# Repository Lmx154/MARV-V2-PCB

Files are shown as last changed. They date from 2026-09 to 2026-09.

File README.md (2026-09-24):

# MARV V2 flight controller

A small RP2354B flight controller for rockets and drones: a 6-axis IMU, a high-g
accelerometer and a barometer on their own buses, native four-bit microSD
logging, USB-C, and an IO block for GPS, ELRS, a magnetometer and servos. Power
conversion from the pack stays **off the board**; the FC takes regulated 5 V (or
USB) and makes its own 3.3 V rails.

**License:** hardware/docs CC0, code 0BSD, no attribution required. Provided
as-is; see [LICENSE.md](LICENSE.md).

Open [MARV-V2.kicad_pro](MARV-V2.kicad_pro) in **KiCad 10**. The repository holds
the schematic and routed board, local footprints and 3D models, offline
datasheets, the design checks, and the input-power simulation. There
is no firmware here.

**Status (2026-09-23): customer-supplied assembly frame exported and verified.** ERC 0,
DRC 0 errors / 0 unconnected / 0 schematic-parity issues. There are 104 DRC
warnings, detailed in the [manufacturing check](reports/manufacturing-check.md).
The [72 × 72 mm manufacturing frame](reports/manufacturing-panel.md) supplies
rails/fiducials for Standard assembly. Review JLCPCB previews before ordering.

[Design specification](DESIGN_SPEC.md) · [GPIO pinout](PINOUT.md) ·
[Libraries](LIBRARIES.md) · [Datasheets](datasheets/README.md) ·
[JLCPCB DFM and routing](reports/jlc-dfm-routing.md) · [Working rules](AGENTS.md)

## The board

| Front | Back |
| :---: | :---: |
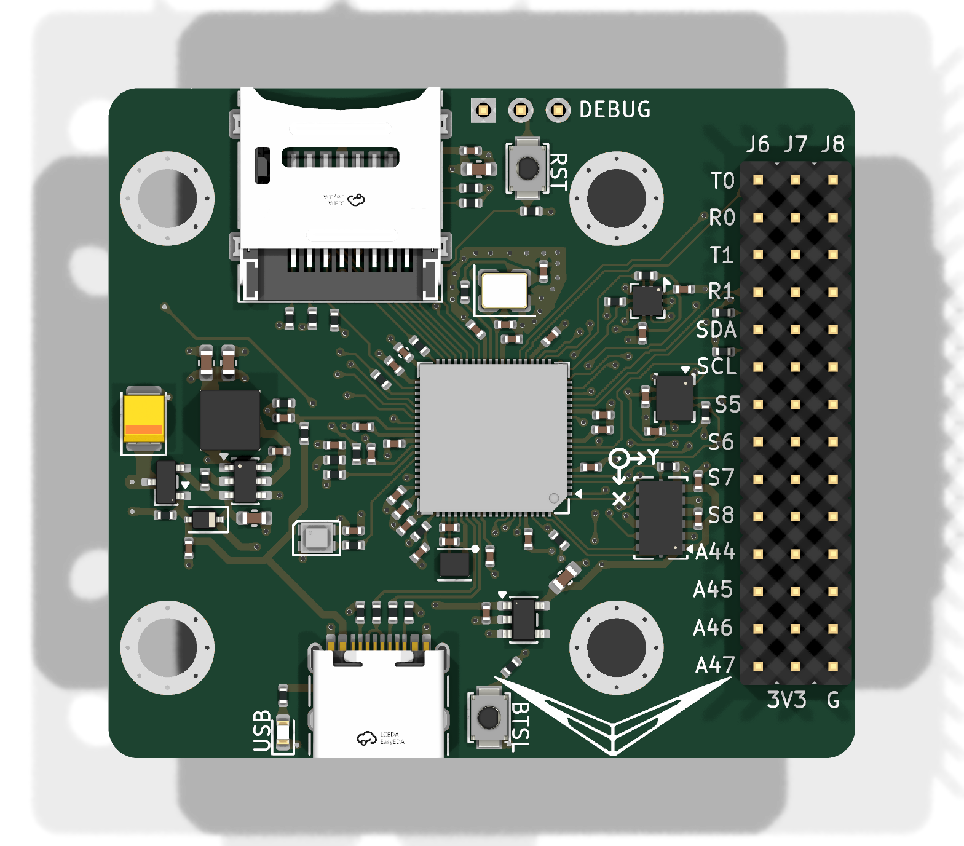
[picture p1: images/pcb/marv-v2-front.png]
MARV V2 PCB front view
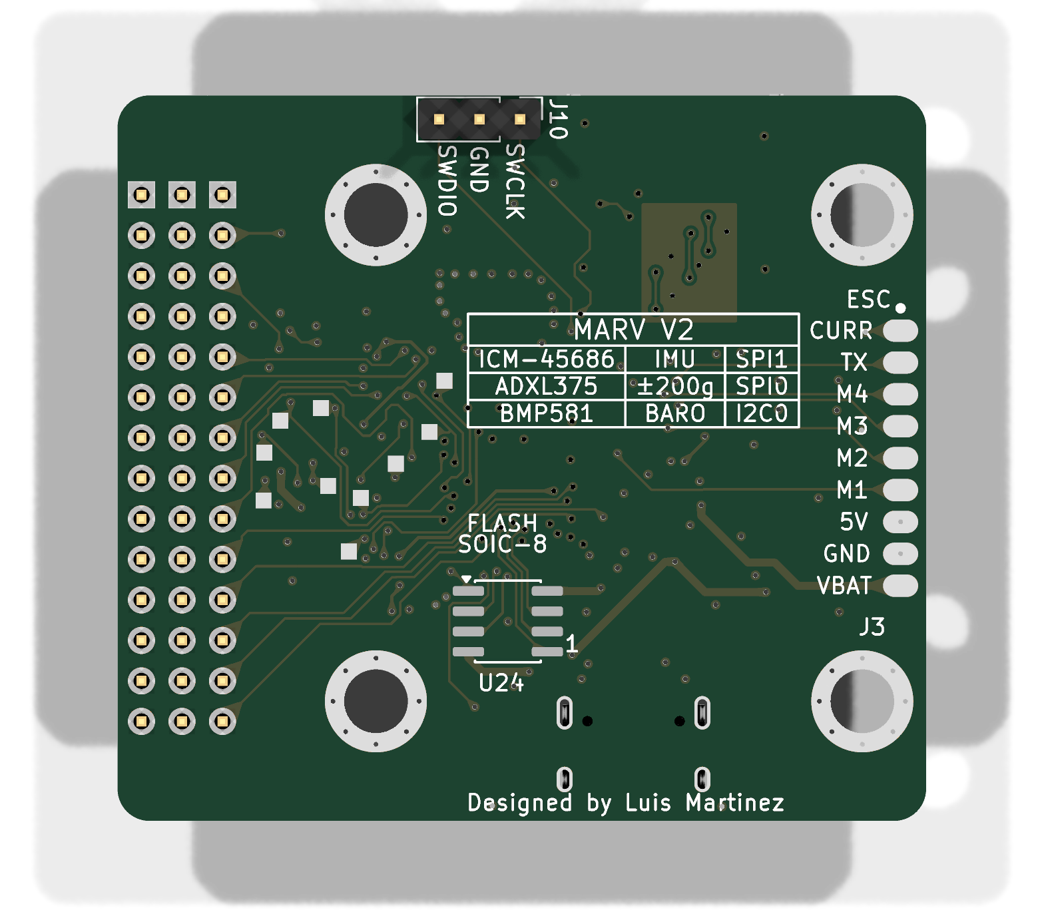
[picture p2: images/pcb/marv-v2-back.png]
MARV V2 PCB back view
|  |  |

3D renders of the saved PCB. Click either image for the full-resolution view.

To refresh both images after saving PCB changes, run:

```sh
python3 tools/render_pcb.py
```

Requires Python 3 and KiCad 10 with its 3D model libraries. The script renders
high-resolution PNGs into `images/pcb/` without modifying the design. Commit the
updated images alongside PCB changes to keep this gallery current.

| | |
|---|---|
| MCU | RP2354B (QFN-80, 2 MB in-package flash), 12 MHz crystal, USB-C device port, WS2812C status LED, RESET and BOOTSEL buttons, SWD header |
| Size / stack | 50.7 × 45.5 mm finished outline (72 × 72 mm manufacturing frame), four layers: F.Cu signals · In1 solid GND · In2 V3V3_SYS plane · B.Cu signals. 1.6 mm FR-4, 1 oz outer / 0.5 oz inner, green mask, HASL |
| Rules | 0.15 mm minimum track and clearance, one via size 0.60 / 0.30 mm, no blind/buried/micro vias — JLCPCB's standard four-layer tier with no paid options |
| Assembly | Front side SMT at JLCPCB (88 placements, 34 unique parts). Back side: ESC pad row J3, SWD header J10, unpopulated QSPI expansion socket U24, test points |
| Mounting | Four M3 grommet holes (4.0 mm) with GND rings |
| Connectors | J3 ESC pads (current, telemetry, PWM1–4, 5 V in, GND, VBAT), J4 USB-C, J6/J7/J8 IO block (14 rows × signal / power / GND), J10 SWD, J11 locking microSD |

## Sensor suite

Every sensor has its own bus; no clock or data net is shared between devices, so
each can be driven at its own rate and no transaction blocks another.

| Ref | Part | What it measures | Bus | Interrupts |
|---|---|---|---|---|
| U21 | InvenSense ICM-45686 | 6-axis IMU (gyro + accel), primary attitude source | hardware **SPI1**, exclusive | INT1, INT2 |
| U23 | Analog Devices ADXL375 | ±200 g accelerometer for launch / impact / hard landings | hardware **SPI0**, exclusive | INT1, INT2 |
| U22 | Bosch BMP581 | barometric altitude and temperature | hardware **I2C0**, address 0x46 | INT |
| J11 | Molex 47219-2001 microSD | flight log | PIO + DMA, native **four-bit SD** | — |

The three sensors run from the dedicated V3V3_ANA rail with their chip-select
and I²C pull-ups referenced to it, and all five interrupt lines land on
independent GPIOs. Layout follows the makers' notes: the BMP581 has no copper or
solder mask under its body (Bosch §8.2), and the inertial sensors sit close to
the MCU with short SPI runs. Exact GPIO numbers are in [PINOUT.md](PINOUT.md).

## Power architecture

```text
2S–6S pack → external 5 V / 3 A buck ─┐
1S 18650   → external 5 V boost ──────┘
                                      ↓ J3 5V_IN            USB-C VBUS
                                      Q1 (AO3401A)           D1 (1N5819WS)
                                      └────────── V5_SYS ────┘
                                                    ├─ AP63203 buck → V3V3_SYS  (MCU, microSD, IO block, LDO enable)
                                                    ├─ TPS7A2033 LDO → V3V3_ANA (ICM-45686, ADXL375, BMP581, ADC_AVDD)
                                                    └─ status LED
RP2354B on-chip switcher: V3V3_SYS → 1.1 V core (laid out per RP2350 datasheet §6.3.8)
Raw pack → J3 VBAT → 100k / 10k divider → ADC (sense only)
```

Nothing that moves is powered through the FC. Motors, servos and ESCs get only
their signal pins; the raw pack voltage arrives for measurement, not for use.
The full boundary table is in [DESIGN_SPEC.md](DESIGN_SPEC.md#sources-and-loads).

## Design decisions

Each of these was a choice with alternatives. The reasons are recorded so they
are not re-litigated by accident.

**External 5 V conversion, no onboard pack buck.** A 2S–6S buck or a 1S boost
already exists in every airframe this board goes into, and an onboard one would
add the hottest, noisiest, most layout-sensitive circuit to a 50 mm board.
The FC takes regulated 5 V and does nothing with the pack except measure it.
Battery charging, protection and cutoff belong to the external system.

**Q1/D1 OR for USB and external power — honestly specified.** A P-FET with its
gate on VBUS plus a Schottky lets the board run on the bench from USB alone and
in the air from the BEC. It does *not* guarantee that the BEC "wins" when both
are present: with USB connected the sources share through D1 and Q1's body
diode and V5_SYS sits lower. That is the circuit's real behaviour, it is what the
simulation shows, and the design accepts it rather than adding a priority mux.

**A separate LDO for the sensors, fed from 5 V.** The inertial sensors and the
barometer see a rail that is not the one the MCU, SD card and IO modules are
switching on. The TPS7A2033 takes its input from V5_SYS (headroom that a 3.3 V →
3.3 V filter cannot give) and its enable from V3V3_SYS, so the sensor rail comes
up after the digital rail. A passive filter was considered and rejected.

**Native four-bit SD over PIO instead of SPI mode.** Logging at flight rates
wants the bandwidth of four data lines and the standard SD command set, and the
RP2354B's PIO can run that bus without touching either hardware SPI block — so
SPI0 stays exclusive to the ADXL375 and SPI1 to the ICM-45686. The cost is six
GPIOs that must sit inside the PIO window (GPIO28–33), five 10 k pull-ups and a
22 Ω series damping resistor on the clock placed at the MCU pin.

**A locking microSD socket ("the latch").** J11 is a hinged-lid connector that is
closed and slid into a locked position over the card: a push-push socket can
eject a card under the shock and vibration of a launch or a hard landing, and a
lost log is the one failure a flight recorder must not have. The trade is that
this socket has no card-detect switch, so the former detect pin and its pull-up
were removed and firmware probes for the card.

**Core-regulator layout by the datasheet.** The RP2354B's 1.1 V core switcher
follows RP2350 datasheet §6.3.8 Figures 23–24: CIN/COUT (C39/C45) in a column
with the LX trace passing between their pads (0402 lands narrowed to a 0.50 mm
gap for that), the inductor's high-current loop closed on the top layer with one
ground connection through two adjacent vias, a copper cutout on In1 under the
inductor and LX net only, the AVDD RC filter, the recommended second 4.7 µF on
the core rail (C81) on the far side of the package, and the polarity-marked
Abracon inductor the datasheet specifies (orientation dot toward pad 2 / DVDD).

**Ordinary four-layer fabrication; spend the budget on components.** 0.15 mm
track/clearance, one 0.60 / 0.30 mm via, HASL, standard copper. The single
exception is a local 0.12 mm clearance rule around C39/C45 so LX can pass the
capacitor pads; that is still inside JLC's 3.5 mil four-layer capability and
costs nothing. No HDI, no filled vias, no impedance control: the USB link is
full-speed, and nothing else on the board is fast enough to need it.

**Through-hole headers shipped unpopulated.** J6–J8 (IO block) and J10 (SWD) are
2.54 mm headers the owner solders; JLC assembles the front SMT side only. J10 is
wired SWCLK–GND–SWDIO to match the Raspberry Pi Debug Probe's 3-pin cable.

**Three GPIOs deliberately unexposed.** GPIO26, 27 and 35 are left unconnected
so the IO block keeps a clean four-spare layout (GPIO44–47); the netlist checker
enforces that they stay that way.

## Validating the power input with simulation

The one thing the board cannot control is how power arrives, so that is the one
thing simulated. `tools/simulate_power_input.py` builds an ngspice deck from the
**saved schematic** (it checks the Q1/D1/C19 wiring before running) and drives
V5_SYS through seven cases: external 5 V only; USB only; both present; USB
plugged in while external stays; USB unplugged; external unplugged; and an
external-only load step. The pass criterion is explicit: the lowest V5_SYS seen
in any event window must stay above the AP63203's 3.8 V input minimum, or the
script exits 1.

```sh
python3 tools/simulate_power_input.py                       # default 0.5 A at V5_SYS
python3 tools/simulate_power_input.py --load 0.3 --usb-voltage 4.75
python3 tools/simulate_power_input.py --load 0.5 --external-load 1.0
```

Latest result ([simulations/RESULTS.md](simulations/RESULTS.md)): lowest event
voltage **4.269 V** during USB removal, margin 0.47 V over the floor; USB-only
operation settles at 4.32 V through D1. Assumptions are stated, not hidden:
0.05 Ω external source, 0.35 Ω USB source, a 0.5 A combined demand that is a
starting point rather than a measured budget, the vendor AO3401A model and a
hand-fitted 1N5819WS curve. It does **not** simulate the downstream regulators,
USB negotiation, sensor noise, layout parasitics or temperature — see
[simulations/README.md](simulations/README.md) for the boundary. Anything
beyond the OR is validated on hardware, not in SPICE.

## Verifying the design

Requirements: Python 3, KiCad 10 with its standard libraries, ngspice. Ordering exports use the installed Fabrication Toolkit plugin.

```sh
mkdir -p build/checks
kicad-cli sch erc --severity-all --exit-code-violations -o build/checks/erc.rpt MARV-V2.kicad_sch
kicad-cli sch export netlist --format kicadxml -o build/checks/netlist.xml MARV-V2.kicad_sch
python3 tools/check_power_netlist.py build/checks/netlist.xml   # rails, all 48 GPIOs, bus endpoints, pull-ups, retired refs
python3 tools/audit_footprints.py build/checks/netlist.xml     # footprint/model availability and pin coverage
python3 tools/dfm.py --check                                   # JLC profile drift (read-only)
kicad-cli pcb drc --schematic-parity --severity-error --severity-warning --format json -o build/dfm/drc.json MARV-V2.kicad_pcb
python3 -m unittest discover -s tests -v                       # DFM tool preservation tests
```

The JLCPCB profile (`config/dfm/jlcpcb.json` and the managed block in
`MARV-V2.kicad_dru`) is applied with `python3 tools/dfm.py --apply` with the PCB
editor closed; it edits only managed settings and never touches placement or
copper. Extra rules live outside the managed block. Netclasses: Signal 0.15 mm,
Default 0.20 mm, LocalPower 0.50 mm, Power 1.0 mm, USB 0.30 mm / 0.20 mm gap.

## Ordering

Use the installed [Fabrication Toolkit](https://github.com/bennymeg/Fabrication-Toolkit)
from KiCad's PCB Editor. Project settings are saved in
[fabrication-toolkit-options.json](fabrication-toolkit-options.json); no custom
Gerber, BOM or placement exporter is needed.

1. Open **MARV-V2-panel.kicad_pro** for the Standard assembly export. This is
   a saved manufacturing copy with customer-supplied rails. After circuit-design
   changes, update the original board, synchronize the manufacturing copy, and
   run the checks before exporting. See the [panel notes](reports/manufacturing-panel.md).
2. Click **Fabrication Toolkit → Generate**. The saved options enable automatic
   component translations and exclude DNP parts. The **User.1 V-cut option is on** for the manufacturing panel. Automatic zone
   refill, alternate outlines and plotting all active layers are **off**. Refill zones
   yourself in KiCad when copper changes require it, before the final DRC.
3. Upload the generated files:

   | JLCPCB step | File |
   | --- | --- |
   | PCB fabrication | `production/MARV-V2-panel.zip` (Gerbers and drills with rails) |
   | Assembly parts | `production/bom.csv` |
   | Assembly placement | `production/positions.csv` |

These three files were regenerated together from the manufacturing panel on
**2026-09-23**. The BOM and placements match the original board; the Gerbers
include the rails, routed channels, V-score annotations and fiducials;
the NPTH drills include tooling holes and the original USB locating holes. The local
`production/order-manifest.json` records source/output SHA-256 hashes, and
`production/SHA256SUMS` checks the three upload files. See the
[panel verification](reports/manufacturing-panel.md) for validation results
and remaining preview checks. Regenerate after any saved design change.

The initial order is **5 PCBs manufactured, 2 assembled on the top side** and
3 bare. Select **1 design, Single PCB, 4 layers, 1.6 mm, green mask, white silk,
HASL (with lead), standard copper and 0.30 mm minimum via holes**. Use
**Standard assembly** and **Edge Rails/Fiducials → Added by Customer**.
The 72 × 72 mm frame contains one finished PCB and uses two full-height
V-scores through its side connections, with no mouse-bite holes or added rail silk. It can be removed after delivery; check the quote no longer includes
JLC's rail-addition service charge.

The schematic's `LCSC` fields and native BOM/position exclusions define the
assembly selection. J6–J8 and J10 are owner-soldered headers; J3, H1–H4,
TP1–TP10 and the graphic footprints are board features; U24 is DNP. All are
omitted from assembly exports. This leaves **88 front-side placements using
34 distinct LCSC parts**. The plugin currently generates 84 BOM rows because
many component values include different descriptive notes; the part selections
are unchanged. JLC's parts-selection page provides current stock and pricing.

Automatic translations apply the plugin's package rotation corrections; they
are export corrections, not changes to the PCB layout. Review every placement
in JLC's preview, especially the custom sensor footprints and **L20: orientation
dot toward pad 2 / DVDD**. The first plugin export was checked against the
previous order files: all 88 part numbers and XY locations matched.

`production/` is generated and ignored by Git. The older `build/fab/`,
`build/assembly/` and `build/MARV-V2-gerbers.zip` outputs are superseded; use the
three plugin files above together. The former `tools/jlc/` scripts and duplicate
CSV inventories were retired; Git history retains them.

## Repository map

| Location | Content |
|---|---|
| `MARV-V2.kicad_*`, `*.kicad_sch` | Project, routed board, custom rules, and the schematic sheets (power OR / 3V3 / VBAT, MCU, IMU, high-g, baro, SD, USB & debug, IO block, QSPI expansion) |
| `DESIGN_SPEC.md`, `PINOUT.md` | Intended circuit and boundaries; every GPIO with its alternates |
| `config/dfm/` | Reviewed JLCPCB profile and custom-rule template |
| `tools/` | Netlist checker, footprint audit, DFM tool, input-power simulation, sheet relinker, netlist fingerprint, PCB image renderer |
| `MARV-V2-panel.kicad_*` | Saved one-board manufacturing frame for Standard assembly with customer-supplied rails |
| `fabrication-toolkit-options.json` | Native Fabrication Toolkit settings for JLCPCB order exports |
| `tests/` | Unit tests for the DFM tool's preservation guarantees |
| `simulations/` | The input-power SPICE deck, its README and the generated results |
| `MARV_Packages.pretty/`, `MARV_Packages.3dshapes/` | Local footprints and STEP models with provenance |
| `datasheets/` | Manufacturer PDFs and a source index |
| `reports/` | Decision and review records — see below |
| `production/`, `build/`, `.dfm-backups/`, `backups/` | Generated output and recovery copies; untracked |

Reports, newest first:

| Report | What it records |
|---|---|
| [manufacturing-panel.md](reports/manufacturing-panel.md) | Customer-supplied V-cut frame, current order package and panel verification |
| [manufacturing-check.md](reports/manufacturing-check.md) | Current manufacturing exports, source verification, DRC warnings and order handoff |
| [electrical-review.md](reports/electrical-review.md) | Review of the saved board before the core-regulator rework |
| [fabrication-cost-audit.md](reports/fabrication-cost-audit.md) | Why the board fits JLC's standard four-layer tier with no upcharges |
| [signal-trace-widths.md](reports/signal-trace-widths.md) | The 55 nets in the 0.15 mm Signal class |
| [jlc-dfm-routing.md](reports/jlc-dfm-routing.md) | JLC capability sources behind every installed constraint |
| [sd-connector-replacement.md](reports/sd-connector-replacement.md) | The locking microSD socket decision and what it removed |
| [communication-architecture.md](reports/communication-architecture.md) | The sensor/SD bus allocation as first made. Its GPIO numbers predate the later pin reorder; [PINOUT.md](PINOUT.md) is authoritative |

Git history keeps the obsolete revisions (onboard pack buck, power mux, buzzer,
earlier connectors); the cleanup baseline is commit `eafe903`. Placement and
routing are done by hand in KiCad and are never regenerated — see
[AGENTS.md](AGENTS.md).

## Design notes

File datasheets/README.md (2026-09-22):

# Component datasheets

Local copies of the manufacturer datasheet for every non-passive part on the board (ICs, discrete
semiconductors, the crystal, connectors/sockets with a specific vendor part, and modules). Purpose:
give any worker a fast, offline reference — `pdftotext <file>.pdf - | less` (or `pdfinfo`) instead of
re-fetching from the web on every question about pinout, decoupling or the application circuit.
Plain passives (R/L/C, ferrite beads), test points and mounting hardware are excluded; see
the schematic values / freshly generated `production/bom.csv` for those.

Two datasheets (`W25Q32JV.pdf`, `APS6404L.pdf`) both cover U24: it is one SOIC-8 socket that takes
either part (DNP by default; see `qspi_expansion.kicad_sch`).

| Refdes | Part | Manufacturer | File | Source URL | Date fetched | Relevant section/page |
|---|---|---|---|---|---|---|
| U20 | RP2354B (RP2350 family, on-package flash) | Raspberry Pi Ltd | `RP2350.pdf` | https://datasheets.raspberrypi.com/rp2350/rp2350-datasheet.pdf | 2026-09-17 | Sec 6.3.8 "External components and PCB layout requirements", p.453 (core-regulator L/C network) |
| U21 | ICM-45686 | TDK InvenSense | `ICM-45686.pdf` | https://www.lcsc.com/datasheet/lcsc_datasheet_2411220643_TDK-InvenSense-ICM-45686_C22459454.pdf (manufacturer page is a gated download form; fetched the LCSC-hosted copy) | 2026-09-17 | Bypass-capacitor table (VDD/VDDIO, 0.1 uF X7R), p.34 |
| U22 | BMP581 | Bosch Sensortec | `BMP581.pdf` | https://www.bosch-sensortec.com/media/boschsensortec/downloads/datasheets/bst-bmp581-ds004.pdf | 2026-09-17 | Pin-out, Figure 22, p.46 |
| U23 | ADXL375BCCZ | Analog Devices | `ADXL375.pdf` | https://www.analog.com/media/en/technical-documentation/data-sheets/ADXL375.PDF | 2026-09-17 | "Power Supply Decoupling", p.26 |
| U7 | AP63203WU-7 | Diodes Incorporated | `AP63203.pdf` | https://www.diodes.com/assets/Datasheets/AP63200-AP63201-AP63203-AP63205.pdf | 2026-09-17 | Figure 21 "Typical Application Circuit of AP63203/AP63205", p.9 (external-component table referenced as "Table 2" in `tools/build_power.py`) |
| U12 | TPS7A2033PDBVR | Texas Instruments | `TPS7A2033.pdf` | https://www.ti.com/lit/ds/symlink/tps7a20.pdf | 2026-09-17 | Sec 7.2 "Typical Application" / Figure 7-4, p.30; Sec 7.4 "Layout", p.31 |
| U24 (fit option A) | W25Q32JVSNIQ (32 Mbit QSPI NOR) | Winbond | `W25Q32JV.pdf` | https://www.winbond.com/resource-files/W25Q32JV%20RevJ%2012242024%20Plus.pdf | 2026-09-17 | Figure 1a, 8-pin SOIC 150-mil pin assignment (package code SN), p.6 |
| U24 (fit option B) | APS6404L-SQN-SN (8 MB QSPI PSRAM) | AP Memory | `APS6404L.pdf` | https://www.apmemory.com/tw/downloadFiles/0324112120g3605268 | 2026-09-17 | Table 1 "Ordering Information" (confirms `-SQN-SN` suffix), p.7 |
| D20 | WS2812C-2020-V1 | Worldsemi | `WS2812C-2020.pdf` | https://www.lcsc.com/datasheet/lcsc_datasheet_2202221130_Worldsemi-WS2812C-2020-V1_C2976072.pdf (LCSC-hosted) | 2026-09-17 | Features / pin function / reflow profile, p.1-2 |
| Q1 | AO3401A | Alpha & Omega Semiconductor | `AO3401A.pdf` | https://www.aosmd.com/pdfs/datasheet/AO3401A.pdf | 2026-09-17 | Pin configuration and electrical characteristics table, p.1-2 |
| D1 | 1N5819WS | Guangdong Hottech | `1N5819WS.pdf` | https://www.lcsc.com/datasheet/lcsc_datasheet_Guangdong-Hottech-1N5819WS_C191023.pdf (LCSC-hosted) | 2026-09-17 | Electrical characteristics (VF, IR), p.1-2 |
| Y1 | 12 MHz TAXM12M4RFBCCT2T | Shenzhen Yajingxin Electronics | `TAXM12M4RFBCCT2T.pdf` | https://www.lcsc.com/product-detail/C133337.html (manufacturer spec sheet, LCSC-hosted) | 2026-09-17 | Specification table (12.000 MHz, CL = 12 pF), p.1 |
| J4 | USB-C receptacle TYPE-C-31-M-12 | Korean Hroparts Elec (HRO Electronics) | `TYPE-C-31-M-12.pdf` | https://www.lcsc.com/product-detail/C165948.html (manufacturer drawing, LCSC-hosted) | 2026-09-17 | Pinout table (A1-A12/B1-B12) and PCB land pattern, p.1 |
| J11 | Molex 47219-2001 / 472192001, C164170, locking hinged microSD | Molex | `472192001.pdf`; `472192001-drawing.pdf` | https://www.es.co.th/Schemetic/PDF/472192001.PDF (Molex part datasheet, generated 2025-04-07); https://cdn.promelec.ru/upload/items/2020/09/01/472192001_sd.pdf (Molex drawing mirror) | 2026-09-17 | Datasheet pp.1–3: hinge type, 8 contacts, no detect switch; drawing p.1: pad layout and pin numbering |
| SW1, SW2 | B3U-1000P tactile switch | Omron | `B3U-1000P.pdf` | https://omronfs.omron.com/en_US/ecb/products/pdf/en-b3u.pdf | 2026-09-17 | Ratings and characteristics table, p.1-2 |

## UNKNOWN

None — all 15 non-passive parts resolved to a verified manufacturer (or manufacturer-authorized
distributor mirror) PDF. Three parts required a fallback from the manufacturer's own site to an
LCSC-hosted copy after the manufacturer link was gated or blocked outbound `curl`/`wget` requests
(see the Source URL column: ICM-45686, WS2812C-2020, 1N5819WS, TAXM12M4RFBCCT2T and
TYPE-C-31-M-12 all use the LCSC-hosted PDF; every other file is the manufacturer's own domain).
Every file was confirmed to start with `%PDF`, exceed 50 kB (the smallest are the two single-sheet
mechanical connector drawings, `TYPE-C-31-M-12.pdf` at ~116 kB and `104031-0811.pdf` at ~100 kB), and
contain the exact part number on an early page via `pdftotext`/`pdfinfo` (and, for `TYPE-C-31-M-12.pdf`,
a rendered-page visual check since that drawing is almost all vector graphics with little extractable
text).

## Locking microSD replacement

J11 now uses Molex 47219-2001 / LCSC C164170. Its manufacturer datasheet and
one-page mechanical drawing are stored above. Both files were verified as PDFs.
The official drawing endpoint timed out during download, so manufacturer content
was retrieved from distributor mirrors. Official drawing URL:
https://www.molex.com/content/dam/molex/molex-dot-com/products/automated/en-us/salesdrawingpdf/472/47219/472192001_sd.pdf

Molex describes the hinged lid and slide-to-lock sequence in its card-socket
brochure: https://www.content.molex.com/dxdam/literature/987651-8263.pdf
The old `104031-0811.pdf` is retained while the saved PCB still uses that socket's
land pattern. Remove it with the old footprint after the owner updates J11.

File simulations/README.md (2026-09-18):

# Input-power simulation

Run `python3 tools/simulate_power_input.py` from the project root. Results are in
[RESULTS.md](RESULTS.md). Requires Python, KiCad CLI and ngspice; no Python packages.

The boundary is external regulated 5 V plus USB, through Q1/D1, to V5_SYS.
External power is either a 2S–6S-to-5 V, 3 A buck or a 1S-18650-to-5 V boost.
Both converters live off-board. Neither raw battery voltage nor charging enters this model.

One deck, [power_input.cir](power_input.cir), runs seven cases: external only,
USB only, both present, USB insertion, USB removal, external removal, and an
external-powered load step. It checks the saved schematic's key power connections
before running. Downstream electronics are one explicit current demand at V5_SYS;
the simulation does not implement fictional buck or LDO control loops.

Default demand is **0.5 A at V5_SYS**, an assumption that can be changed:

```sh
python3 tools/simulate_power_input.py --load 0.3
python3 tools/simulate_power_input.py --load 0.5 --external-load 1.0
python3 tools/simulate_power_input.py --usb-voltage 4.75
```

`--external-load` is additional electronics demand on 5V_IN, before the OR.
The external source's 3 A rating is its capacity, not the board's assumed draw.
Source resistances are explicitly assumed: external 0.05 ohm, USB 0.35 ohm.
The external boost's output rating and both converters' transient behavior need
actual module specifications or measurements; cell current ratings do not supply those.

The report shows V5_SYS voltage and source/reverse currents. The 3.8 V comparison
is the AP63203's specified minimum input, not a pass/fail test for the whole board.
Exit 1 means a simulated event falls below that input range. Solver/check errors
also fail the command. Exact generated decks, logs and waveform tables stay in a
printed temporary directory; they do not multiply tracked project files.

Q1 uses the existing AOS model. D1 uses the existing hand-fitted forward curve;
its temperature-dependent leakage is not bounded. Capacitors are nominal and the
white LED curve is approximate. Source current limiting, charging, cell cutoff,
USB negotiation, regulator outputs, noise, layout and thermal behavior are outside scope.
In particular, this simulation cannot decide whether sensor supplies need an LDO.

Historical simulation revisions are available in Git history. Only the current
input-network deck and its required models are maintained here.

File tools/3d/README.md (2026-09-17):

# STEP model inspection

`bbox.py` is the reusable FreeCAD helper for inspecting model dimensions and
alignment while changing footprints or importing replacement models.

```sh
/snap/bin/freecad.cmd -c tools/3d/bbox.py -- FILE.step </dev/null
```

With no STEP arguments it inspects local models in `MARV_Packages.3dshapes/`
and its `_incoming/` directory. It prints bounding coordinates, dimensions,
centers, solid counts and face counts without changing the files.

Requires FreeCAD. Keep inputs under the repository for the snap's filesystem
access. KiCad model and footprint Y axes differ; see the script's coordinate
notes when interpreting offsets.

The four one-time package generators have been removed. Their STEP assets and
[provenance](../../MARV_Packages.3dshapes/PROVENANCE.md) remain available.

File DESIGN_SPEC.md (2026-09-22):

# MARV V2: intended circuit

The goal is a simple flight controller for rockets/drones, using external power
conversion and familiar flight-controller circuitry. The supplied madflight
FC3v2 reference is a simplicity/layout reference, not a requirement to copy every
component. Owner-confirmed decisions in this document supersede older design notes.

## Power architecture

```text
2S–6S pack → external 5 V / 3 A buck ─┐  alternative external sources
1S 18650 → external 5 V boost ────────┘
                                    ↓
                              J3.7 / 5V_IN (BEC input only; no header row)
                                    ↓ Q1
USB VBUS ──────────────────── D1 ──→ V5_SYS
                                      ├─ AP63203 buck → V3V3_SYS
                                      │                  ├─ MCU, microSD, optional QSPI
                                      │                  ├─ GPS/ELRS/MAG and spare IO
                                      │                  └─ LDO enable
                                      ├─ TPS7A2033 LDO → V3V3_ANA → onboard sensors / ADC_AVDD
                                      └─ RGB status LED

Raw battery → J3.9 / VBAT → 100k / 10k divider → MCU voltage measurement
```

The analog LDO takes its **input from V5_SYS**, not from the 3.3 V buck.
Its **enable** comes from V3V3_SYS. This retains headroom for a regulated 3.3 V
sensor supply. The owner chose to retain this small stage after considering a
passive filter. External daughterboard demand stays off the analog rail.

No onboard pack buck, battery charger, battery current shunt, power mux IC, or
custom regulator-control simulation is required. Battery charging and converter
protection/cutoff belong to the external system.

## Sources and loads

| Item | Agreed boundary |
| --- | --- |
| 2S–6S option | External buck supplies regulated 5 V, rated 3 A. The FC receives its output. |
| 1S option | External boost supplies regulated 5 V. The cell is not wired directly to the OR. Boost output rating and transient behavior are not yet specified. |
| 18650, owner-provided specifications | 4.2 V charged / 3.6 V nominal / 2.5 V discharge cutoff; charge 3 A standard / 9 A maximum with 60 °C cutoff; discharge 30 A continuous with 80 °C cutoff / 36 A maximum rating. These are external-system specifications, not functions implemented by this PCB. |
| USB | VBUS supplies the FC through D1. USB current availability must cover the attached electronics; the simulation does not implement negotiation or a host current limit. |
| System 3.3 V | MCU, storage and external module/IO power. The AP63203 is a 2 A regulator; that rating is not a measured board load budget. |
| Sensor 3.3 V | ICM-45686, BMP581, ADXL375 and MCU ADC_AVDD, supplied by U12. |
| Actuators | Owner clarified 2026-09-18: no servos, motors or actuators are powered from FC pads. Only their PWM/control signals use the FC. Existing 5V_IN pad connections remain, but no actuator current is included in the FC trace budget. |

The new simulation uses an explicit **0.5 A combined demand at V5_SYS** as a
starting assumption. This is neither 0.5 A on each downstream rail nor a demand
for the external converter to deliver its full 3 A rating. Choose actual module
loads before assigning a final system/USB budget. A daughterboard having its own
LDO does not by itself establish that its power input accepts 3.3 V; that input
range remains a module-selection requirement.

Expected external electronics may include four ToF sensors, several lidar modules,
GPS and an ELRS radio. Their exact voltage requirements and simultaneous peak
current remain to be established. The routing defaults and fabrication constraints
are documented in [JLCPCB DFM and routing](reports/jlc-dfm-routing.md).

## OR behavior

Q1 is an AO3401A: drain on 5V_IN, source on V5_SYS, gate on USB_VBUS.
D1 is a 1N5819WS: anode on USB_VBUS, cathode on V5_SYS. C19 is 100 uF
on the external input, upstream of Q1.

With USB absent, Q1's gate discharges and its channel carries the external supply.
With USB present, Q1 can be off and the sources can share through D1 and Q1's
body diode. **There is no guaranteed BEC priority or lossless switchover.**
A lower V5_SYS when USB is connected is consistent with this circuit; the old
expectation that the BEC always wins through Q1's low-resistance channel was wrong.

The USB-only path does not intentionally feed external 5V_IN. 5V_IN reaches no
header row: all fourteen J7 power pins are V3V3_SYS, so every IO block module can
operate on USB alone. Model leakage is
not a guarantee of zero reverse current under every temperature and source condition.

## Connectors

J3 pads 1–9: **CURR, TX, M4, M3, M2, M1, 5V_IN, GND, VBAT**.
VBAT is sense-only. ESC current is read from its analog output; the FC has no
propulsion-current pass-through or shunt. J10 is the SWD 1x03 2.54 mm header (SWCLK, GND, SWDIO — Debug Probe order).

For the IO block, each row has J6 = signal, J7 = power, J8 = ground:

| Rows | Signals | J7 supply |
| --- | --- | --- |
| 1–2 | GPS UART | V3V3_SYS |
| 3–4 | ELRS UART | V3V3_SYS |
| 5–6 | Magnetometer I2C | V3V3_SYS |
| 7–10 | PWM5–8, servo signals only | V3V3_SYS |
| 11–14 | GPIO44–47, spare IO | V3V3_SYS |

All signal IO is 3.3 V logic. J3 carries PWM1–4 to the ESC.
See [PINOUT.md](PINOUT.md) for individual MCU assignments.

## Sensor and storage communication

ADXL375 has exclusive hardware SPI0 (SCK GPIO2, MOSI GPIO3, MISO GPIO4, CS GPIO14).
ICM-45686 has exclusive hardware SPI1 (SCK GPIO10, MOSI GPIO11, MISO GPIO8, CS GPIO7).
Both selects have 10k pull-ups to the sensors' V3V3_ANA supply. Clock and data
signals have no pull resistors. ADXL INT1/INT2 use GPIO1/21; ICM INT1/INT2 use
GPIO6/18. All interrupt nets remain independent.

BMP581 uses I2C0 (SCL GPIO9, SDA GPIO12), each with a 4.7k pull-up to V3V3_ANA.
CSB is tied to VDDIO and SDO/ADDR to GND, selecting I2C address 0x46. BARO_INT
uses GPIO13. Existing sensor decoupling and power circuitry are retained.

microSD uses PIO + DMA native four-bit SD: DAT0–DAT3 GPIO28–31, CLK GPIO32,
CMD GPIO33, on the MCU's top-left corner facing J11. All six signals need the
PIO GPIO16–47 window, which the LED and ESC PIO signals already require. CMD
and all four data lines have 10k external pull-ups to V3V3_SYS. GPIO32 drives
SD_CLK through R58, 22 ohm nominal (0–33 ohm tuning range), to be placed next
to the MCU pin. There is no clock pull resistor. J11 is the Molex 47219-2001 / C164170 locking hinged-lid connector. It has no
card-detect switch; R41 is removed.
LED_DATA is on GPIO43. The ESC signals are ordered on the MCU's left edge to
match J3 top to bottom: ESC_TELEM_RX GPIO34, PWM4–PWM1 GPIO36–39, then
CURR_SENSE on ADC1 (GPIO41) and VBAT_SENSE on ADC2 (GPIO42); VBUS_SENSE stays
on ADC0. GPIO26, GPIO27 and GPIO35 are the unexposed spares. External connector
assignments are retained. See [PINOUT.md](PINOUT.md) for every GPIO and routing priorities.

This is a hardware allocation; no firmware is implemented. The board carries
these nets and parts as routed (2026-09-22).

## Board and validation scope

Owner cost requirement (2026-09-21): keep ordinary four-layer fabrication and
spend the budget on components. Retain 0.15 mm minimum traces/clearance,
0.60/0.30 mm through vias, standard 1.6 mm FR-4 and copper weights, green mask,
and the selected HASL finish. Do not introduce precision drills, HDI vias,
resin-filled/capped vias or other paid fabrication upgrades to resolve routing
congestion. See [signal widths](reports/signal-trace-widths.md) and the
[fabrication cost audit](reports/fabrication-cost-audit.md). Final CAM acceptance
and the actual quote remain required; project settings alone cannot guarantee price.

RP2354B MCU; ICM-45686 IMU; BMP581 barometer; ADXL375 high-g sensor;
microSD; optional unpopulated backside QSPI expansion. Four copper layers,
front-side SMT assembly, with backside solder pads/test points and the DNP
expansion land. Existing placement is retained. The owner will route the board manually in KiCad. Agents must not route,
autoroute, stitch planes or rebuild the layout.

The active simulation checks **power arriving at V5_SYS only**. It does not
predict sensor noise, regulator-loop stability, enclosure temperature or flight
performance. See [simulation results](simulations/RESULTS.md).

Routing and DRC are complete (2026-09-22: 0 errors, 0 unconnected, 0 parity).
Remaining work is off the board: confirm physical ESC pad pitch; select the
external converters and compatible 3.3 V modules; review JLC assembly rotations
in the ordering preview; then measure source transitions, supply noise during
module/SD activity, and temperatures on hardware. These checks do not mandate
additional circuit features unless they reveal an actual problem.

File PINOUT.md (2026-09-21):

# MARV V2 GPIO reference

The schematic records the wiring. Keep this reference and `tools/check_power_netlist.py` aligned
when changing GPIOs. Power assignments
for the IO block are in [DESIGN_SPEC.md](DESIGN_SPEC.md).

Source: RP2350 Datasheet, Section 1.2.3, Table 3 "General Purpose Input/Output (GPIO) Bank 0 Functions"
(F1 SPI, F2 UART, F3 I2C, F4 PWM, F5 SIO, F6-F8 PIO0/1/2, F9 clock/QMI/trace, F10 USB, F11 UART aux).
ADC0-7 are GPIO40-47 on the RP2350B/RP2354B (QFN-80) only. All GPIO are 3.3 V, not 5 V tolerant.

External IO leaves the board on the J6/J7/J8 IO block (right front edge, signal/power/GND columns), plus
two solder-pad rows on the back (B.Cu): the ESC pad row J3 and the DBG pads J10.

## Table A — every GPIO

| GPIO | Net | Used as | Datasheet alternates (F1 SPI / F2 UART / F3 I2C / F4 PWM / F9-F11) | Status |
| --- | --- | --- | --- | --- |
| 0 | FLASH_CS1 | QMI CS1n (F9) | SPI0 RX, UART0 TX, I2C0 SDA, PWM0 A, USB OVCUR DET | assigned (flash/PSRAM socket U24) |
| 1 | ADXL_INT1 | GPIO input (ADXL INT1) | SPI0 CSn, UART0 RX, I2C0 SCL, PWM0 B, USB VBUS DET | assigned |
| 2 | ADXL_SCK | SPI0 SCK (F1) | PWM1 A, SPI0 SCK, UART0 CTS, I2C1 SDA, USB VBUS EN, UART0 TX (F11) | assigned |
| 3 | ADXL_MOSI | SPI0 TX (F1) | PWM1 B, SPI0 TX, UART0 RTS, I2C1 SCL, USB OVCUR DET, UART0 RX (F11) | assigned |
| 4 | ADXL_MISO | SPI0 RX (F1) | PWM2 A, SPI0 RX, UART1 TX, I2C0 SDA, USB VBUS DET | assigned |
| 5 | PWM8 | PWM2 B (F4) | SPI0 CSn, UART1 RX, I2C0 SCL, USB VBUS EN | assigned (servo S8) |
| 6 | ICM_INT1 | GPIO input (ICM INT1) | I2C1 SDA, SPI0 SCK, UART1 CTS, PWM3 A, USB OVCUR DET, UART1 TX (F11) | assigned |
| 7 | ICM_CS | GPIO (ICM CS) | I2C1 SCL, SPI0 TX, UART1 RTS, PWM3 B, USB VBUS DET, UART1 RX (F11) | assigned |
| 8 | ICM_MISO | SPI1 RX (F1) | UART1 TX, I2C0 SDA, PWM4 A, QMI CS1n, USB VBUS EN | assigned |
| 9 | BARO_SCL | I2C0 SCL (F3) | UART1 RX, SPI1 CSn, I2C0 SCL, PWM4 B, USB OVCUR DET | assigned |
| 10 | ICM_SCK | SPI1 SCK (F1) | PWM5 A, UART1 CTS, I2C1 SDA, USB VBUS DET, UART1 TX (F11) | assigned |
| 11 | ICM_MOSI | SPI1 TX (F1) | PWM5 B, UART1 RTS, I2C1 SCL, USB VBUS EN, UART1 RX (F11) | assigned |
| 12 | BARO_SDA | I2C0 SDA (F3) | UART0 TX, SPI1 RX, I2C0 SDA, PWM6 A, CLOCK GPIN0, USB OVCUR DET | assigned |
| 13 | BARO_INT | GPIO in | UART0 RX, SPI1 CSn, I2C0 SCL, PWM6 B, CLOCK GPOUT0, USB VBUS DET | assigned |
| 14 | ADXL_CS | GPIO (ADXL CS) | PWM7 A, SPI1 SCK, UART0 CTS, I2C1 SDA, CLOCK GPIN1, USB VBUS EN, UART0 TX (F11) | assigned |
| 15 | PWM7 | PWM7 B (F4) | SPI1 TX, UART0 RTS, I2C1 SCL, CLOCK GPOUT1, USB OVCUR DET, UART0 RX (F11) | assigned (servo S7) |
| 16 | ELRS_RX | UART0 TX (F2) | SPI0 RX, I2C0 SDA, PWM0 A, USB VBUS DET | assigned (J6 R1) |
| 17 | ELRS_TX | UART0 RX (F2) | SPI0 CSn, I2C0 SCL, PWM0 B, USB VBUS EN | assigned (J6 T1) |
| 18 | ICM_INT2 | GPIO input (ICM INT2) | SPI0 SCK, UART0 CTS, I2C1 SDA, PWM1 A, USB OVCUR DET, UART0 TX (F11) | assigned |
| 19 | PWM6 | PWM1 B (F4) | SPI0 TX, UART0 RTS, I2C1 SCL, QMI CS1n, USB VBUS DET, UART0 RX (F11) | assigned (servo S6) |
| 20 | PWM5 | PWM2 A (F4) | SPI0 RX, UART1 TX, I2C0 SDA, CLOCK GPIN0, USB VBUS EN | assigned (servo S5) |
| 21 | ADXL_INT2 | GPIO input (ADXL INT2) | SPI0 CSn, UART1 RX, I2C0 SCL, PWM2 B, CLOCK GPOUT0, USB OVCUR DET | assigned |
| 22 | MAG_SDA | I2C1 SDA (F3) | SPI0 SCK, UART1 CTS, PWM3 A, CLOCK GPIN1, USB VBUS DET, UART1 TX (F11) | assigned (J6 SDA) |
| 23 | MAG_SCL | I2C1 SCL (F3) | SPI0 TX, UART1 RTS, PWM3 B, CLOCK GPOUT1, USB VBUS EN, UART1 RX (F11) | assigned (J6 SCL) |
| 24 | GPS_RX | UART1 TX (F2) | SPI1 RX, I2C0 SDA, PWM4 A, CLOCK GPOUT2, USB OVCUR DET | assigned (J6 R0) |
| 25 | GPS_TX | UART1 RX (F2) | SPI1 CSn, I2C0 SCL, PWM4 B, CLOCK GPOUT3, USB VBUS DET | assigned (J6 T0) |
| 26 | — (unexposed spare, no-connect) | GPIO | SPI1 SCK, UART1 CTS, I2C1 SDA, PWM5 A, USB VBUS EN, UART1 TX (F11) | spare, not exposed (no-connect). Was SD_CLK_MCU; the SD bus moved to GPIO28–33 so it meets J11 from the MCU's top-left corner |
| 27 | — (unexposed spare, no-connect) | GPIO | SPI1 TX, UART1 RTS, I2C1 SCL, PWM5 B, USB OVCUR DET, UART1 RX (F11) | spare, not exposed (no-connect). Was SD_CMD |
| 28 | SD_DAT0 | PIO native SD DAT0 | SPI1 RX, UART0 TX, I2C0 SDA, PWM6 A, USB VBUS DET | assigned |
| 29 | SD_DAT1 | PIO native SD DAT1 | SPI1 CSn, UART0 RX, I2C0 SCL, PWM6 B, USB VBUS EN | assigned |
| 30 | SD_DAT2 | PIO native SD DAT2 | SPI1 SCK, UART0 CTS, I2C1 SDA, PWM7 A, USB OVCUR DET, UART0 TX (F11) | assigned |
| 31 | SD_DAT3 | PIO native SD DAT3 | SPI1 TX, UART0 RTS, I2C1 SCL, PWM7 B, USB VBUS DET, UART0 RX (F11) | assigned |
| 32 | SD_CLK_MCU | PIO native SD clock, through R58 to SD_CLK | SPI0 RX, UART0 TX, I2C0 SDA, PWM8 A, USB VBUS EN | assigned |
| 33 | SD_CMD | PIO native SD command | SPI0 CSn, UART0 RX, I2C0 SCL, PWM8 B, USB OVCUR DET | assigned |
| 34 | ESC_TELEM_RX | PIO UART RX | SPI0 SCK, UART0 CTS, I2C1 SDA, PWM9 A, USB VBUS DET, UART0 TX (F11) | assigned (ESC TX pad) |
| 35 | — (unexposed spare, no-connect) | GPIO | SPI0 TX, UART0 RTS, I2C1 SCL, PWM9 B, USB VBUS EN, UART0 RX (F11) | spare, not exposed (no-connect) |
| 36 | PWM4 | DShot via PIO | SPI0 RX, UART1 TX, I2C0 SDA, PWM10 A, USB OVCUR DET | assigned (ESC M4) |
| 37 | PWM3 | DShot via PIO | SPI0 CSn, UART1 RX, I2C0 SCL, PWM10 B, USB VBUS DET | assigned (ESC M3) |
| 38 | PWM2 | DShot via PIO | SPI0 SCK, UART1 CTS, I2C1 SDA, PWM11 A, USB VBUS EN, UART1 TX (F11) | assigned (ESC M2) |
| 39 | PWM1 | DShot via PIO | SPI0 TX, UART1 RTS, I2C1 SCL, PWM11 B, USB OVCUR DET, UART1 RX (F11) | assigned (ESC M1) |
| 40 | VBUS_SENSE | ADC0 | SPI1 RX, UART1 TX, I2C0 SDA, PWM8 A, USB VBUS DET | assigned |
| 41 | CURR_SENSE | ADC1 | SPI1 CSn, UART1 RX, I2C0 SCL, PWM8 B, USB VBUS EN | assigned (ESC CURR pad) |
| 42 | VBAT_SENSE | ADC2 | SPI1 SCK, UART1 CTS, I2C1 SDA, PWM9 A, USB OVCUR DET, UART1 TX (F11) | assigned |
| 43 | LED_DATA | PIO (WS2812C, window 16–47) | SPI1 TX, UART1 RTS, I2C1 SCL, PWM9 B, USB VBUS DET, UART1 RX (F11) | assigned |
| 44 | IO_GPIO44 | GPIO / ADC4 | SPI1 RX, UART0 TX, I2C0 SDA, PWM10 A, USB VBUS EN | spare, on IO block row 11 |
| 45 | IO_GPIO45 | GPIO / ADC5 | SPI1 CSn, UART0 RX, I2C0 SCL, PWM10 B, USB OVCUR DET | spare, on IO block row 12 |
| 46 | IO_GPIO46 | GPIO / ADC6 | SPI1 SCK, UART0 CTS, I2C1 SDA, PWM11 A, USB VBUS DET, UART0 TX (F11) | spare, on IO block row 13 |
| 47 | IO_GPIO47 | GPIO / ADC7 | SPI1 TX, UART0 RTS, I2C1 SCL, PWM11 B, QMI CS1n, USB VBUS EN, UART0 RX (F11) | spare, on IO block row 14 |

## Table B — spare GPIOs

Four exposed GPIOs remain on J6 rows 11–14: GPIO44–47. GPIO26, GPIO27 and GPIO35 are
unexposed and have no-connect flags. All other GPIOs have assigned functions.

| GPIO | Exposed | Useful alternates | Constraint |
| --- | --- | --- | --- |
| 44 | J6 row 11 | ADC4, PWM10 A, UART0 TX | SPI1 and I2C0 already serve onboard sensors |
| 45 | J6 row 12 | ADC5, PWM10 B, UART0 RX | Hardware UART0 already serves ELRS |
| 46 | J6 row 13 | ADC6, PWM11 A | PWM11 A is shared with GPIO38 |
| 47 | J6 row 14 | ADC7, PWM11 B | PWM11 B is shared with GPIO39 |
| 26 | No | PWM5 A, SPI1 SCK, PIO, GPIO | Needs a schematic connection before use |
| 27 | No | PWM5 B, SPI1 TX, PIO, GPIO | Needs a schematic connection before use |
| 35 | No | PWM9 B, PIO, GPIO, UART0 RX (F11) | Needs a schematic connection before use |

SPI0 and SPI1 are dedicated to ADXL375 and ICM-45686 respectively. I2C0 serves
BMP581; I2C1 serves the external magnetometer. No unused hardware SPI, I2C or UART
controller remains. Pin alternate functions do not create extra controllers.

## Table C — peripheral ledger

| Peripheral | GPIOs | Device / hardware requirement |
| --- | --- | --- |
| SPI0 | SCK 2, MOSI/TX 3, MISO/RX 4; CS 14 | ADXL375 only, four-wire SPI; R51 10k CS pull-up to V3V3_ANA |
| SPI1 | SCK 10, MOSI/TX 11, MISO/RX 8; CS 7 | ICM-45686 only; R48 10k CS pull-up to V3V3_ANA |
| I2C0 | SCL 9, SDA 12 | BMP581 only; R50/R57 4.7k to V3V3_ANA; address 0x46 |
| I2C1 | SDA 22, SCL 23 | MAG on J6, existing R25/R26 4.7k to V3V3_SYS |
| Native four-bit SD, PIO + DMA | DAT0–DAT3 28–31, CLK 32, CMD 33 | J11 only; R58 22 ohm between SD_CLK_MCU and SD_CLK; R36–R40 10k CMD/data pull-ups to V3V3_SYS |
| Sensor interrupts | ADXL INT1 1 / INT2 21; ICM INT1 6 / INT2 18; BARO INT 13 | Five separate nets and GPIOs; no combining |
| Card detect | — | Molex 47219-2001 has no detect switch; no GPIO is used |
| UART0 | TX 16, RX 17 | ELRS on J6 |
| UART1 | TX 24, RX 25 | GPS on J6 |
| Servo PWM | 20, 19, 15, 5 | PWM5–8, unchanged external connections |
| ESC outputs | 39, 38, 37, 36 | PWM1–4 in J3 pad order; intended PIO DShot, unchanged external connections |
| ADC | 40, 41, 42 | VBUS (ADC0), ESC current (ADC1), battery voltage (ADC2) |
| Other PIO | ESC telemetry RX 34; RGB LED 43 | GPIO16–47 window |
| QMI CS1 | 0 | Optional U24 expansion, unchanged |
| USB, SWD | Dedicated pins | J4, J10, unchanged |

## Hardware constraints

- SD DAT0–DAT3 are consecutive in ascending GPIO order (a PIO `in pins` requirement).
  All six SD signals use GPIO28–33 on the MCU's top-left corner facing J11, which
  puts the SD state machine in the GPIO16–47 PIO window. The LED and ESC PIO
  signals require the same window, so every PIO user shares GPIOBASE = 16. These are hardware
  allocation constraints; this change supplies no PIO or DMA firmware.
- BMP581 CSB is hard-wired to V3V3_ANA (its VDDIO), and SDO/ADDR to GND for
  7-bit address 0x46. The BMP581_I2C symbol models pin 5 as an address input.
- Sensor pulls use the sensor supply, V3V3_ANA. SD pulls use V3V3_SYS.
  No pulls are fitted on either sensor SPI clock/data bus or on SD_CLK.
- Place R58 next to U20 GPIO32 (pin 40) during the owner's PCB update. Its nominal value
  is 22 ohm; the intended tuning range is 0–33 ohm. Keep the MCU-to-resistor stub short.
- Routing priority: ICM SPI, ADXL SPI, SD clock/native bus, then BMP581 I2C.
  Keep signals short over continuous GND. Avoid split references, switching-node
  copper, long parallel runs beside servo/pyro power, unnecessary vias and long stubs.
- PWM frequency is shared per slice. Servo S5/S8 share slice 2; the ESC hardware-PWM
  fallback puts M4/M3 on slice 10 (shared with IO_GPIO44/45) and M2/M1 on slice 11
  (shared with IO_GPIO46/47). PIO DShot does not use those PWM slices.
- GPIO26, GPIO27 and GPIO35 remain unconnected; update this document and the netlist
  checker together if either is assigned. External connector pin assignments are retained.

## Revision boundary

This communication update changes the schematic only. The PCB retains its previous
nets and placement until the owner updates it from the schematic. R57 and R58 are
new parts; R50 changes from 10k on BARO_CS to 4.7k on BARO_SCL. TP5 now probes BARO_SDA.
To free GPIO2/3/4 for SPI0, ICM_INT2 moves from GPIO2 to GPIO18, LED_DATA from GPIO3
to GPIO33, and ADXL_CS from GPIO4 to GPIO14. The SD clock and command move from
GPIO33/34 to GPIO26/27. ADXL_INT2 is newly connected to GPIO21.

References: [RP2350 datasheet, GPIO function table and PIO GPIOBASE](https://datasheets.raspberrypi.com/rp2350/rp2350-datasheet.pdf),
[BMP581 datasheet, protocol selection and I2C wiring](https://www.bosch-sensortec.com/media/boschsensortec/downloads/datasheets/bst-bmp581-ds004.pdf).

The locking-connector revision selects Molex 47219-2001 / LCSC C164170 for J11.
R41 and SD_DET are removed because this connector has no detect switch.
The eight card contacts and native SD GPIO26–31 connections are unchanged.

Pin-order revision (2026-09-20): GPIOs on the MCU's left and top-left edges are
re-ordered so traces meet J3 and J11 without detours. J3 top to bottom is now
ESC_TELEM_RX GPIO34, PWM4–PWM1 GPIO36–39, CURR_SENSE ADC1 (GPIO41), VBAT_SENSE
ADC2 (GPIO42). The SD bus is DAT0–DAT3 GPIO28–31, CLK GPIO32, CMD GPIO33; LED_DATA
is GPIO43; GPIO26, GPIO27 and GPIO35 become the no-connect spares. No connector
pinout, net name or part changes; the owner updates the PCB from the schematic.

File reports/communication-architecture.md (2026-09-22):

# Sensor and native SD schematic update

> **Historical (2026-09-17).** The bus allocation below is as first made; the GPIO
> numbers predate the later MCU pin reorder (SD is now GPIO28–33, spares GPIO26/27/35).
> [PINOUT.md](../PINOUT.md) and [DESIGN_SPEC.md](../DESIGN_SPEC.md) are authoritative.

Validated 2026-09-17 using KiCad 10.0.6. Hardware/schematic only; no firmware or
PCB edits. Open the saved `MARV-V2.kicad_sch` project hierarchy; generated PDF/netlist
snapshots have been removed and can be re-exported from KiCad. The full GPIO reference is [PINOUT.md](../PINOUT.md).

## Electrical allocation

| Interface | Net | RP2354B GPIO | MCU pad | Device pin |
| --- | --- | --- | --- | --- |
| ADXL375, hardware SPI0 | ADXL_SCK | 2 | 79 | U23.14 SCL/SCLK |
| | ADXL_MOSI | 3 | 80 | U23.13 SDA/SDI |
| | ADXL_MISO | 4 | 1 | U23.12 SDO |
| | ADXL_CS | 14 | 13 | U23.7 CS |
| | ADXL_INT1 | 1 | 78 | U23.8 INT1 |
| | ADXL_INT2 | 21 | 21 | U23.9 INT2 |
| ICM-45686, hardware SPI1 | ICM_SCK | 10 | 8 | U21.13 AP_SCLK |
| | ICM_MOSI | 11 | 9 | U21.14 AP_SDI |
| | ICM_MISO | 8 | 6 | U21.1 AP_SDO |
| | ICM_CS | 7 | 4 | U21.12 AP_CS |
| | ICM_INT1 | 6 | 3 | U21.4 INT1 |
| | ICM_INT2 | 18 | 18 | U21.9 INT2/FSYNC/CLKIN |
| BMP581, hardware I2C0 | BARO_SCL | 9 | 7 | U22.2 SCL |
| | BARO_SDA | 12 | 11 | U22.4 SDA |
| | BARO_INT | 13 | 12 | U22.7 INT |
| microSD, PIO + DMA native four-bit SD | SD_CLK_MCU → R58 → SD_CLK | 26 | 27 | J11.5 CLK |
| | SD_CMD | 27 | 28 | J11.3 CMD |
| | SD_DAT0 | 28 | 36 | J11.7 DAT0 |
| | SD_DAT1 | 29 | 37 | J11.8 DAT1 |
| | SD_DAT2 | 30 | 38 | J11.1 DAT2 |
| | SD_DAT3 | 31 | 39 | J11.2 DAT3 |
| Card detect | None on Molex 47219-2001 | 35 unconnected | 44 | No detect pins |

The SD data GPIOs are consecutive and all six bus signals fit in GPIO26–31,
inside the GPIO16–31 overlap of both PIO windows. SPI0 serves ADXL375 only;
SPI1 serves ICM-45686 only. No sensor or microSD clock/data net is shared.

## Bias, mode selection and damping

| Nets | Resistors | Value | Supply |
| --- | --- | --- | --- |
| ADXL_CS, ICM_CS | R51, R48 | 10k each | V3V3_ANA |
| BARO_SCL, BARO_SDA | R50, R57 | 4.7k each | V3V3_ANA |
| SD_CMD, SD_DAT0–SD_DAT3 | R36–R40 | 10k each | V3V3_SYS |
| SD_CLK_MCU to SD_CLK | R58 | 22 ohm series; tuning range 0–33 ohm | No pull resistor |

BMP581 CSB (U22.6) is hard-wired to VDDIO/V3V3_ANA and ADDR/SDO (U22.5) to
GND, selecting I2C with 7-bit address 0x46. Its new `BMP581_I2C` symbol variant
models the address pin as an input; the generic symbol is preserved. There are
no pulls on either sensor SPI clock/data bus, no clock pull on SD, and no bus
pull-downs. All five sensor interrupt signals terminate at distinct MCU GPIOs.

R50 is repurposed from the former 10k barometer CS pull-up to a 4.7k SCL pull-up.
R57 and R58 are new 0402 parts. TP5 now probes BARO_SDA. Sensor decoupling,
sensor/system power separation and card decoupling are retained. The subsequent
locking-connector update removes the old card-detect circuit.

## Validation

- KiCad ERC: **0 errors, 0 warnings**. Re-run the README check commands for current results.
- Freshly exported netlist: all 48 GPIO assignments and every bus's
  exact endpoint set pass `tools/check_power_netlist.py`. The checks include
  chip-select pull-ups, I2C pull-up values and rail, I2C mode/address straps,
  consecutive SD data GPIOs, PIO window, independent interrupts, and the clock
  resistor's two separate nets with no pull or bypass.
- Fault injection into temporary netlists confirmed that the checker rejects
  a clock pull resistor, shared SPI data, a missing SD pull-up, a wrong I2C
  pull-up value, and combined sensor interrupt lines.
- `tools/audit_footprints.py`: **107 components OK**, including the new J11 model.
- Compared every pre-existing pin against the starting netlist: each connection
  is unchanged or matches an explicitly intended bus/GPIO reassignment. Existing component UUID paths are retained. The bus revision added R57/R58;
  the locking-connector revision changes the J11 footprint and removes R41.
- Power, external IO, USB/debug and root schematic files remain byte-identical
  to the starting workspace. QSPI sheet changes are annotation-only, removing
  its obsolete description of the microSD interface.
- Rendered MCU, ICM, ADXL, BMP581 and microSD pages were visually reviewed.
- PCB file is byte-identical to the starting workspace. SHA-256:
  `2b4a53d8f419f890fc76ce7563b38e38ff1111ec8dd953fc5a8fe4f6d3b97b4e`.

## PCB handoff

The owner must update the PCB from the schematic, add R57/R58 and route it.
The PCB still contains the previous communication connections. Place R58
physically next to U20 GPIO26 with a short source stub.

Routing priority: ICM SPI, ADXL SPI, SD clock/native bus, BMP581 I2C. Keep these
signals short and direct over continuous ground, away from switching-node
copper and external power wiring. Avoid unnecessary vias
and long stubs. The current DFM profile uses the common 0.20 mm signal class for these buses.

LED_DATA moved GPIO3 → GPIO33; ICM_INT2 moved GPIO2 → GPIO18; ADXL_CS moved
GPIO4 → GPIO14. SD clock/command moved GPIO33/34 → GPIO26/27. ADXL_INT2 now
uses GPIO21. GPIO34, GPIO35 and GPIO37 remain unconnected; GPIO44–47 remain exposed
spares. External connector assignments are unchanged.

Manufacturing exports and earlier PCB reports remain tied to the old PCB and
must be regenerated after the owner's layout update. The current schematic
component inventory is in the saved schematic; Fabrication Toolkit exports `production/bom.csv`.

## Manufacturer references

- [RP2350 datasheet](https://datasheets.raspberrypi.com/rp2350/rp2350-datasheet.pdf):
  Section 1.2.3 GPIO alternate functions and PIO GPIOBASE (0 or 16).
- [BMP581 datasheet](https://www.bosch-sensortec.com/media/boschsensortec/downloads/datasheets/bst-bmp581-ds004.pdf):
  Sections 5.1, 5.6 and 6.2.3, I2C protocol selection, address strap and wiring.
- Offline sensor datasheets and source index: [datasheets/README.md](../datasheets/README.md).

## Locking microSD connector update

J11 is now Molex 47219-2001 / LCSC C164170, a hinged socket with a lid that
slides to lock. The manufacturer datasheet is saved at
[datasheets/472192001.pdf](../datasheets/472192001.pdf), with its
[mechanical drawing](../datasheets/472192001-drawing.pdf).
The connector has no detect switch: R41 and SD_DET are removed and GPIO35
becomes an unconnected spare. Native SD CLK/CMD/DAT0–DAT3, power, shield
ground and the required pulls/damping are unchanged.

Latest checks: ERC zero violations; all 48 GPIO and exact bus-net checks pass;
107 components have matching footprint pads. An exact-part LCSC/EasyEDA 3D model is now stored locally and attached to
the new footprint. All 107 components pass the footprint/model audit.

The PCB is unchanged. Replace its J11 footprint and remove R41 when updating
from the schematic; the locking connector is not footprint-compatible with
the old socket. Provide lid-opening access and verify the lid is slid fully
into the locked position. This replacement does not establish a measured
rocket-flight shock/vibration qualification.

Subsequent 3D update: J11 now displays the locking-socket model on the PCB.
Only its model reference/transform changed; PCB pads, nets and placement
remain as before. Use KiCad's 3D viewer for a current preview; model appearance does not validate pad compatibility.

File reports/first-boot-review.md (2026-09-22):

# First-boot review — 2026-09-22

Scope: the saved PCB and schematic, narrowed at the owner's request to faults
that could prevent the first prototype from powering up, booting, or being
programmed. No placement, routing, zones, schematic, project settings, or tracked
simulation outputs were changed. Checks used saved copper fills, without refill.

**Verdict: no definite first-boot blocker found.** The design looks reasonable
for a first prototype. This is a design-review result, not measured startup proof.

## Checks completed

- KiCad 10.0.6 ERC: **0 violations**.
- PCB DRC: **0 errors, 0 unconnected items, 0 schematic-parity issues**.
  There are 104 warnings; these concern pad-size assertions, silkscreen and
  missing courtyards on graphics, not reported electrical shorts or opens.
- Critical netlist checker: passed 193 pin mappings, all 48 GPIO allocations,
  power-source connections, and connector mappings. Footprint audit: 108/108 pass.
- Q1/D1 input polarity, U7 fixed-3.3-V feedback/enable, and U12 input/output/enable
  connections match the intended architecture. Regulator input/output capacitors,
  bootstrap capacitor and inductors are present and connected.
- MCU I/O, USB, core and analog supplies, exposed ground pad, core-feedback
  connection, and VREG_AVDD RC filter are connected as intended.
- The earlier core-regulator finding has been addressed: the saved In1.Cu plane
  has a cutout beneath L20/VREG_LX, and C39/C45 and PGND have a local front-layer
  return path. L20 is at approximately **(98.15, 109.60) mm**. C81 supplies the
  additional bulk decoupling on the far side of the MCU.
- RUN has its pull-up and reset switch; BOOTSEL pulls QSPI_SS down through R24.
  USB D+/D−, the two separate 5.1 kΩ CC resistors, and J10 SWCLK/GND/SWDIO are
  connected correctly. USB signal routes are continuous on the front layer.
- The specified MCU is **RP2354B**, which includes boot flash; leaving optional
  U24 unpopulated does not remove the primary boot memory.
- Y1, R21 and C46/C47 form the intended 12 MHz crystal network; no open or swapped
  clock connection was found.

## Two remaining first-boot considerations

1. **Verify L20's physical orientation in the assembly preview.** Fit the specified
   AOTA-B201610S3R3-101-T with the orientation dot toward **pad 2 / DVDD**. A generic
   two-pad footprint and CPL rotation alone do not establish the physical winding
   orientation. No evidence here proves that it is reversed.
2. **Crystal startup remains unmeasured.** Y1 is TAXM12M4RFBCCT2T, CL 12 pF, with
   two 18 pF capacitors and a 1 kΩ drive resistor. This is plausible, but is a
   different crystal from Raspberry Pi's qualified reference. If supplies and RUN
   are correct but USB BOOTSEL does not enumerate, check the oscillator early;
   SWD is available for diagnosis. This is not a demonstrated need to change parts.

Manufacturer basis: [RP2350 datasheet](https://datasheets.raspberrypi.com/rp2350/rp2350-datasheet.pdf),
sections 6.3.8, 8.2.1.1 and 14.3; local [selected crystal datasheet](../datasheets/TAXM12M4RFBCCT2T.pdf).

## Input-power cross-check

The existing input-only model was run without overwriting its tracked report:

| Assumed V5_SYS demand | USB source | Lowest event-window V5_SYS |
| --- | --- | --- |
| 0.1 A | 5.0 V | 4.339 V |
| 0.5 A | 5.0 V | 4.269 V |
| 0.5 A | 4.75 V | 4.065 V |

All exceed the AP63203's 3.8 V input minimum under the model's assumptions.
These are simulations of the input OR, not evidence that either regulator output
or the assembled board has been tested. Source current limits and startup loads
are not established by this model.
Source: [AP63203 datasheet](https://www.diodes.com/assets/Datasheets/AP63200-AP63201-AP63203-AP63205.pdf).

## First prototype check

Initially leave the SD card and external modules disconnected. Verify V3V3_SYS
and V3V3_ANA near 3.3 V, DVDD near 1.1 V, and RUN high; then test USB BOOTSEL
and load a minimal program before adding peripherals.

Raw results: `build/final-review/erc.rpt`, `drc.json`, `netlist.xml`,
`geometry.json` and `power-results.json`. The read-only DFM comparison also noted
an extra 0.30 mm routing-width preset; this is not a first-boot issue.

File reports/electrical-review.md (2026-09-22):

# Saved-board electrical review — 2026-09-21

Reviewed the PCB saved at 21:05:34 local time after the owner's via-clearance
cleanup. Read-only design review: no routes, placements, zones, schematic content
or project rules were changed. Checks used existing zone fills; no refill was run.

No definite fatal wiring fault was found. This is not a guarantee of startup,
regulator stability, signal integrity or assembly yield. The core regulator below
is the main issue to resolve before fabrication.

## Verified results

- Schematic ERC: **0 violations**.
- PCB DRC: **0 unconnected items; 0 schematic-parity issues**. No reported copper
  shorts, copper-clearance errors, hole-clearance errors or solder-mask bridges.
- Remaining DRC: **78 courtyard-spacing errors and 80 small-MCU-land warnings**.
  This run reported no silkscreen violations.
- Every courtyard finding reports a positive gap (smallest 0.0221 mm between
  courtyards). These violate additional project spacing margins, not reported
  physical courtyard intersections. They still need assembly review; do not
  move decouplers away from ICs solely to satisfy excessive spacing margins.
- The project's connection checker passed 193 critical pin mappings, all 48 GPIO
  allocations, power/USB polarity, connector assignments and pad coverage for
  107 components. It checks intended connections, not analog performance.
- RP2354B power/ground, RC-filtered VREG_AVDD, RUN pull-up/reset, BOOTSEL path,
  USB D+/D- and both USB-C CC resistors have the intended connections.
- The optional U24 remains DNP; RP2354B has internal flash, so an unpopulated
  U24 is not a missing boot-memory fault. SWD is available on J10.
- Sensor buses and pull-ups, native SD mapping/pull-ups and its clock resistor
  match the saved schematic and intended allocation.
- The MCU has the expected 0.4 mm pitch and 3.4 mm exposed ground pad. Its
  0.20 mm-wide peripheral lands trigger a generic 0.25 mm review threshold;
  Raspberry Pi's recommended footprint itself uses 0.22 mm lands. These generic
  warnings are not evidence that the package cannot be manufactured. Final
  HASL/fine-pitch assembly and orientation still need the assembly preview.

## 1. Core regulator: resolve before fabrication

**Confirmed deviation:** the filled In1.Cu ground plane is present immediately
under L20 and the VREG_LX route. There is no local plane cutout or rule area.
Copper occupancy was checked at (98.05,109.15), (97.55,109.15), (97.30,108.00)
and (97.80,106.50) mm. L20 is centered at (98.05,109.15).

Raspberry Pi explicitly calls for removing copper immediately below the inductor
and switching node on the adjacent layer of a multilayer board. This is a local
cutout around the regulator, not a reason to remove ground under unrelated signals.

The complete C39/L20/C45 return loop also merits comparison against the reference:
C39 GND returns via (100.60,110.25); C45 GND via (98.194518,106.961548);
VREG_PGND via (97.30,105.15). The high-current ground returns are distributed
through the plane rather than the reference's compact common-ground arrangement.
Connectivity is correct; parasitic impedance and coupling remain unverified.
Do not simply widen LX everywhere: the manufacturer also asks to minimize its
copper/parasitics. Keep C41's analog filter return separate from switching current.

**Consequence:** possible unstable/noisy core supply or load-dependent resets;
not proof that the board will fail to boot. This is the highest-priority layout
risk found in the review. Follow the reference layout locally and verify L20's
winding-dot orientation in the actual assembly preview. A generic two-pad inductor
footprint and zero-degree placement do not prove the physical dot orientation.
No claim is made that the present assembled orientation is definitely reversed.

Source: [RP2350 datasheet](../datasheets/RP2350.pdf), section 6.3.8 and figures
23–24 (printed pages 454–455; PDF pages 455–456).
[Abracon inductor drawing and polarity marking](https://abracon.com/datasheets/AOTA-B201610S3R3-101-T.pdf)

## 2. Crystal: startup qualification remains open

Y1 is TAXM12M4RFBCCT2T (12 MHz, CL 12 pF, ESR at most 60 ohms), with C46/C47
18 pF and R21 1 kilohm. XIN/XOUT connectivity is correct. Two 18 pF capacitors
provide 9 pF series load before board/pin parasitics; that is plausible for a
12 pF crystal, but it does not establish oscillation margin or drive level.

This is an alternative to Raspberry Pi's validated ABM8-272-T3 network. Either
use the recommended crystal with its recommended network, or establish startup
and drive-level margins for this exact alternative across supply and temperature.
Do not blindly change the capacitors to another board's values.

**Consequence:** a nonstarting oscillator could prevent normal USB BOOTSEL and
application startup. No evidence was found that this particular crystal is
certain to fail; it is a qualification risk, not a confirmed wiring defect.

Sources: [selected crystal datasheet](../datasheets/TAXM12M4RFBCCT2T.pdf);
[Raspberry Pi crystal recommendation](https://www.raspberrypi.com/news/rp2350-now-available-at-jlcpcb/).

## 3. Barometer: sensor-performance concern, not a dead-board fault

U22 uses ordinary per-pad mask openings; no footprint graphic opens the whole
under-body mask area. Bosch recommends no solder mask beneath BMP581 and warns
that material contacting the body can affect performance. Its landing-pattern
section also discourages under-body tracks and vias.

Review U22's mask/landing pattern against Bosch section 8.2 before assembly.
This does not imply the MCU or the rest of the board will be dead, but pressure
measurement quality matters for this controller.
Source: [BMP581 datasheet](../datasheets/BMP581.pdf), section 8.2.

## Other observations and limits

USB has the correct nets, CC resistors and 27-ohm series resistors. The actual
MCU-side routes are about 11.9/12.0 mm long at 0.20 mm width. The series resistors
are nearer the connector than the MCU; Raspberry Pi recommends them near the MCU.
This is a signal-integrity departure, not a demonstrated 12 Mbps USB failure.
Neither differential impedance nor USB compliance was measured here.

The 5 V input and 3.3 V rails have not been load/transient tested, and no final
external-module current budget was supplied. ERC/DRC do not validate those limits.
The existing input-only simulation does not test either regulator's real stability.
No new circuitry or performance promises are inferred from it.

Full local check results: `build/review/electrical-drc.json` and
`build/review/electrical-erc.json`. The owner's PCB geometry was preserved.

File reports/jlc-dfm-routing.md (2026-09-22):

# MARV V2 — JLCPCB DFM and routing setup

Verified against published JLCPCB information on **2026-09-18**, using KiCad **10.0.6**.
Signal defaults were updated on **2026-09-21**: see the
[exact 55-net list](signal-trace-widths.md) and the current
[fabrication cost audit](fabrication-cost-audit.md). The board/parity counts and
unfinished schematic-transfer notes below describe the older September 18 audit.
Settings live in `MARV-V2.kicad_pro`, `MARV-V2.kicad_dru`, and the board setup.
The reusable source profile is `config/dfm/jlcpcb.json`, with custom rules in
`config/dfm/jlcpcb.kicad_dru`. Run `python3 tools/dfm.py --check` to detect drift
or `--apply` to restore those managed settings with backups. Keep owner rules
outside the marked block; rules after it may override the profile and need review.

**The constraints are installed; the existing board is not ready for fabrication.**
The saved PCB is behind the schematic and needs the owner's schematic-to-PCB
update before routing. No footprints, pads, nets, board edges, tracks or zones were
changed by this work. The only PCB-file edits are green solder-mask color metadata.

## Order configuration and cost

Use the existing **four copper layers, 1.6 mm FR-4, 1 oz outer / 0.5 oz inner
copper, green mask, ordinary tented through vias**. Keep the existing standard
7628-style stackup: 0.2104 mm prepreg between each outer layer and its adjacent
inner layer, 1.065 mm core, 0.0152 mm inner copper. The project's 0.035 mm outer
copper is nominal. JLC uses a different finished-copper thickness for impedance
modeling, so match its calculator to the actual order stackup. These are purchasing
choices as well as KiCad metadata: a Gerber upload does not place the order with
these settings automatically. [JLC stackup information](https://jlcpcb.com/help/article/multi-layer-pcb-standard-laminated-structures)

**Surface finish is HASL (with lead) by owner choice (2026-09-21) for cost; ENIG was the earlier default.** HASL has a lower bare-board price, but the
0.4 mm-pitch MCU and LGA sensors make planarity and bridging relevant. ENIG is the
recommended practical compromise for this already-selected component set, not a
claim that it is JLC's absolute cheapest finish. No heavy copper, microvias,
blind/buried vias, resin fill, copper capping, edge plating or custom stackup is
needed by these rules. [JLC HASL guidance](https://jlcpcb.com/blog/how-to-resolve-short-circuit-hasl)

Select **Economic PCBA, front-side population** where the quote permits it. Its
published limits include 0402 passives and 0.4 mm IC pitch; this board is at the
latter limit. Leave U24 DNP and fit the through-hole IO headers yourself if that
reduces assembly cost. Economic assembly does not require adding board fiducials
or tooling rails. Component selection, quantity, reflow compatibility and the
actual quote still determine eligibility and price; no order was submitted.
[JLC assembly capabilities](https://jlcpcb.com/capabilities/pcb-assembly-capabilities)

## Installed fabrication constraints

All dimensions below are **mm**, edge-to-edge unless identified otherwise. These
are the applied project limits, often deliberately more generous than JLC's
absolute process limit.

| Check | Applied value |
|---|---:|
| Track width minimum | 0.15 |
| Different-net copper clearance, including track/pad | 0.15 |
| Copper to routed outline | 0.30 |
| Via diameter / finished drill | 0.60 / 0.30 (JLC free tier "0.3mm/(0.4/0.45mm)", recommended 0.15 mm ring) |
| Via annular ring / plated-pad annular ring | 0.15 / 0.15 radial |
| Drill to unrelated copper | 0.25 (JLC via minimum 0.20 plus margin); PTH pads 0.35 |
| Via hole to hole | 0.25 |
| Hole spacing involving drilled pads | 0.45 |
| NPTH round hole / NPTH slot minimum | 0.50 / 1.00 |
| Plated slot minimum | 0.50 |
| Drilled hole to SMD land, including same-net | 0.20 |
| Mask expansion / minimum web | 0.00 / 0.10 |
| Mask opening to neighboring copper | 0.09 |
| Silkscreen clearance / stroke / text height | 0.15 / 0.15 / 1.00 |

JLC's published multilayer trace/space floor is 0.09/0.09; SMD pad spacing is
0.15. The chosen 0.15 rules provide margin. The via presets use JLC's free via tier: the order form prices by the
smallest hole, and selecting 0.2 mm added ~$38 of high-precision extras on the
2026-09-21 quote regardless of pad size, so 0.3 mm holes are the floor here. No universal maximum trace width is imposed: wide copper
is allowed when other clearances hold. [JLC fabrication capabilities](https://jlcpcb.com/capabilities/pcb-capabilities)

Silkscreen on the board is normalised for JLC rather than in the source libraries:
every silk stroke is 0.15 mm, silk text is 1.0 mm / 0.15 mm, 0402 passives and L2
carry no silk outline, and test points use the project's compact footprint. The
resulting library-mismatch warnings are therefore set to ignore in the profile.

Solder-mask openings expose solderable copper; **zero expansion does not put mask
on the pads**. Zero expansion and the 0.10 mm web were already present and are
retained. Pads keep their existing paste apertures; there is no blanket paste
shrink. Vias remain tented on both sides, with no fill or cap. Tenting is not a
substitute for filled/capped via-in-pad construction. Existing manufacturer-specific
pad or footprint overrides must be checked during the final mask/paste review.

New-zone defaults use 0.20 clearance, 0.20 minimum thickness, 0.25 thermal gap and
0.30 thermal spokes. They do not create or refill any zone. Review actual spoke
width, count, necks and return paths when the owner adds planes.

## Component spacing and limitations of DRC

There is no general trace-to-component-body clearance: a masked trace may pass
under many packages. Clearance to their **copper pads** is enforced electrically;
package-specific restrictions take precedence.

JLC's assembly spacing recommendations depend on package pairs. For example,
0402-to-0402 is 0.15, 0603-to-0603 is 0.18, SOT-to-SOT is 0.40, and QFN-to-chip is
1.00. These are component-boundary measurements, not courtyard measurements.
[JLC spacing table and measurement diagram](https://jlcpcb.com/help/article/minimum-spacing-for-smd-components)

KiCad checks **courtyard-to-courtyard** spacing. To avoid pretending these are exact
body measurements, this project uses explicit conservative targets:

| Pair includes | Required courtyard gap |
|---|---:|
| Ordinary packages | 0.18 |
| C19 | 0.35 |
| Q1, U7 or U12 (SOT) | 0.40 |
| U24 (SOIC) | 0.50 |
| U20–U23 (QFN / LGA) against another IC (U*, Q*) | 1.00 |

Chip passives and inductors next to U20–U23 use the ordinary 0.18 row: with the
0402 and QFN courtyard margins that is already ~1.0 mm body-to-body, the top of
JLC's 0.4–1.0 chip-to-QFN range, and the RP2350 core-regulator parts must sit
against the MCU.

The last applicable row takes precedence. LGA uses the QFN value as an engineering
proxy; JLC's table does not separately specify these exact sensors. Since a proper
courtyard already contains body/land margin, these targets are **stricter** than
component-edge requirements. A failure is a placement-review request, not proof
JLC cannot assemble it. Before moving tightly placed decouplers, compare actual
body/land spacing with the table and the IC layout recommendations. Do not shrink
courtyards merely to clear errors. New packages need review; this is a rule set
for MARV V2, not a universal JLC library. Missing courtyards produce warnings.
[KiCad custom-rule semantics](https://docs.kicad.org/10.0/en/pcbnew/pcbnew.html#custom-design-rules)

Features still needing manual/CAM review include slots drawn as outline cutouts,
slot aspect ratio and cutter radius, narrow same-net gaps, copper slivers, filled
silkscreen shapes, stencil apertures and assembly rotations. A global same-net
physical-clearance rule is not used because intended trace junctions and pad
connections must remain possible. The board is configured for routed edges;
V-scored panel edges need separate review. DRC also cannot establish temperature,
load transients, impedance, or solder-joint yield.

## Signal and power widths, one USB pair

Use **netclass width** in the router. Nets select their default automatically.
The width menu contains **0.15, 0.20, 0.50 and 1.00**; the differential-pair menu has
one **0.30 width / 0.20 gap** entry. The only via preset is **0.60 / 0.30**;
all netclasses use it. The zero entries
in the project preset arrays are KiCad's netclass/default selectors, not zero-width
copper. The 0.15 signal width is the existing fabrication floor, not a relaxed rule.

| Netclass | Width | Nets / use |
|---|---:|---|
| Signal | 0.15 | 55 exact digital/control nets: SPI, I2C, UART, SD, QSPI, PWM, SWD, LED data, MCU_RUN and BOOT_BTN; see [net list](signal-trace-widths.md) |
| Default | 0.20 | Crystal, ADC sense, regulator control/bootstrap, USB CC, indicator current and unclassified nets |
| LocalPower | 0.50 | USB_VBUS, V3V3_ANA, DVDD, VREG_LX, VREG_AVDD, GND |
| Power | 1.00 | 5V_IN, V5_SYS, V3V3_SYS, U7_SW |
| USB | 0.30, gap 0.20 | USB_DP/DM and their RP/MCU-side names |

PWM does not need a special thick class. VBAT is sense-only and does not need a
power width. U7_BST is a local bootstrap connection, not a supply trunk. Ground's
0.50 default is for short connections; use the intended ground plane for returns.

**Widths are routing defaults, not mandatory minimum widths on every branch.**
A 1.00 mm trunk must neck down at small pads. Use 0.20 near MCU/sensor pins and
0.50 at regulator and diode lands, widening promptly. Keep necks short and inspect
the complete load path. A small decoupler branch does not carry the whole rail
current. Avoid widening immediately beside adjacent fine-pitch pads.

Measured minimum pad dimensions from the saved board:

| Component group | Narrow pad dimension | Practical entry |
|---|---:|---|
| U20 RP2354B | 0.20 | 0.20 |
| U21 ICM-45686 | 0.35 | 0.20 |
| U22 BMP581 | 0.30 | 0.20 |
| U23 ADXL375 | 0.25 | 0.20 |
| J4 USB signal pins | 0.30 | 0.30, or short 0.20 escape |
| U7 / U12 / Q1 | 0.60 | 0.50 |
| D1 | 0.45 | 0.20 neck or carefully oriented 0.50 entry |
| L20 | 0.55 | 0.50 |

The 0.20 entries in the pad table describe the previous pad-entry choice; the
listed Signal nets now use 0.15 mm, including entries at those pads. Power pad
entries are unchanged. Neither width is datasheet-mandated or universally
impedance-optimal.
J11 in the saved board is still the old 104031 socket; these settings do not
substitute for transferring the new 47219 footprint from the schematic.

## Power budget and width rationale

Owner clarification: **no servos, motors or actuators are powered through the FC**.
Possible loads are four ToF sensors, several lidar modules, GPS and ELRS.
The existing 5 V pad connections remain as drawn. External electronics use the
system rail, not the quiet onboard sensor rail. Check each module's input voltage
and simultaneous peak current once the exact models are selected.

The 2 A AP63203 rating is an upper device rating, not spare current guaranteed at
the headers. MCU, storage and modules share it. The input-only simulation's 0.5 A
V5_SYS assumption is also not a measured load budget. D1 is a 1 A-class part, so
USB input must not be treated as a 2 A source; available host current and diode
heating require their own check.

For a first-pass comparison, with 35 µm outer copper, a 50 mm straight trace and
copper resistivity 1.724e-8 ohm·m at 20 °C:

| Width | Resistance | Example drop |
|---|---:|---:|
| 0.20 | 123 mΩ | 12 mV at 0.10 A |
| 0.50 | 49 mΩ | 49 mV at 1 A |
| 1.00 | 25 mΩ | 49 mV at 2 A |

These calculations exclude pads, vias, connections and the ground return. At the
published minus-20% width tolerance, resistance increases by 25%. A legacy
IPC-2221 outer-trace estimate at 10 °C rise gives about 1.45 A for 0.50 mm and
2.39 A for 1.00 mm (about 2.03 A after that width reduction). This supports the
presets as starting points, not a thermal qualification. Do not apply the outer
trace estimate to the thinner inner copper or to bottlenecks in zones.
[JLC explanation of the estimation method](https://jlcpcb.com/blog/pcb-trace-width-guide)

Use broad copper where available for shared supply paths. Review parallel vias
for substantial rail current; one generic via is not automatically rated for the
whole 2 A rail. No thermal vias or plane stitching were added.

## Datasheet findings that matter while routing

- **RP2354B:** the core regulator is the critical layout. Follow section 6.3.8 and
  its switching-current loop drawing; keep L20 and its input/output capacitors on
  the same side, minimize VREG_LX copper, maintain the specified ground returns,
  and avoid copper immediately below L20/LX on the adjacent layer. VREG_AVDD is
  noise-sensitive. The 0.50 preset cannot enforce this topology.
  [Local RP2350 datasheet](../datasheets/RP2350.pdf)
- **USB:** RP2350 is full speed, 12 Mbps; Raspberry Pi still recommends a 90 Ω
  differential path and an uninterrupted ground reference. Keep the existing
  series resistors. The 0.30/0.20 pair is a starting geometry for the saved
  four-layer stackup, **not verified controlled impedance**. Confirm it with
  JLC's calculator using the actual stackup, finished copper and mask before
  committing the USB route. Keep connector-to-resistor and resistor-to-MCU paths
  balanced; do not assume KiCad combines their separate nets for skew checks.
  [Raspberry Pi hardware design guide, USB section](https://datasheets.raspberrypi.com/rp2350/hardware-design-with-rp2350.pdf)
- **AP63203:** use compact input/switch/output loops and short capacitor returns.
  Its layout section recommends 2 oz copper for a 2 A application. Keeping the
  lower-cost 1 oz process therefore requires checking temperature at the actual
  load; full 2 A continuous operation has not been demonstrated on this board.
  Use 1.00 mm/shared copper where it fits and short 0.50 mm pin entries.
  [AP63203 layout section](../datasheets/AP63203.pdf)
- **TPS7A2033:** a 300 mA sensor LDO, with close input/output capacitors and copper
  area for heat spreading. The 0.50 default is ample for its intended local
  branches; thermal dissipation still depends on voltage drop and actual load.
  [TPS7A20 section 7.4](../datasheets/TPS7A2033.pdf)
- **ICM-45686 / ADXL375 / BMP581:** ordinary 0.15 mm signal traces are the default for
  routing geometry. ICM SPI supports up to 24 MHz and ADXL SPI up to 5 MHz; short
  paths, decoupling and quiet returns matter more than making signal copper wide.
  Keep the separate SPI buses and interrupt nets from the current schematic.
  [ICM](../datasheets/ICM-45686.pdf), [ADXL](../datasheets/ADXL375.pdf)
- **BMP581 exception:** Bosch asks for 0.20 mm pad spacing, no traces/vias beneath
  the sensor, and no mask under the sensor body with 20 µm horizontal mask
  clearance. Its pad-spacing rule is installed, but its existing footprint has
  ordinary separate mask openings: **the under-body mask and keepout arrangement
  still needs a footprint review**. Do not apply global mask shrinking as a fix.
  This can affect sensor performance even when generic fab DRC passes.
  [BMP581 section 8.2](../datasheets/BMP581.pdf)
- **SD / optional QSPI:** 0.15 mm is the chosen signal starting point, not a
  speed guarantee. Keep clock/data over a continuous reference and avoid stubs.
  Place SD clock R58 as required by the current schematic. Socket mechanics do
  not define the card's timing budget; select clock rates after the actual path
  is known. W25Q32JV and APS6404L have different command/frequency limits and
  loads; populating U24 later requires timing review.
  [Winbond](../datasheets/W25Q32JV.pdf), [AP Memory](../datasheets/APS6404L.pdf),
  [new Molex socket](../datasheets/472192001-drawing.pdf)
- **Crystal / GPIO / LED / switches / sense dividers:** the explicit logic and
  MCU-button nets use 0.15 mm; crystal, analog sense and LED supply/current nets
  retain their previous defaults. See the exact net list before changing copper.
  Keep crystal and high-impedance analog paths short and away from switch nodes;
  width does not replace capacitance/noise review.

## Validation and next routing steps

Run `python3 tools/dfm.py --drc` for a fresh read-only check in
`build/dfm/drc.json`. The counts below are the 2026-09-18 baseline; the full
snapshot is recoverable from commit `01a357c`. The original board
had 5 reported layout violations, 302 unconnected items and 185 schematic-parity
issues. With the installed checks it has:

| Result | Count |
|---|---:|
| Layout errors | 182 |
| Layout warnings | 206 |
| Unconnected items | 302 |
| Schematic-parity issues | 185 |

The 388 layout findings comprise 131 text-size/stroke errors, 51 conservative
courtyard-gap errors, 119 graphic-stroke warnings, 80 MCU-pad-size review warnings,
2 silk overlaps and 5 silk/edge warnings. The 80 MCU lands are below JLC's generic
0.25 mm minimum SMD-pad dimension; their manufacturer footprint and the supported
0.4 mm assembly pitch need a package-specific CAM check. **Do not enlarge the
MCU pads to make this warning disappear.**

Parity includes two missing footprints, one extra footprint, 61 net conflicts,
32 footprint/symbol mismatches and 89 field mismatches. Resolve these through
KiCad's schematic-to-PCB update before routing; the report preserves the item
references. No exclusions were added to hide errors.

A disposable synthetic board additionally verified detection of undersized vias,
annular rings, microvias, via-in-pad, drilled-pad spacing, PTH-to-copper clearance,
undersized NPTH holes and narrow tracks. This caught a condition unsupported by
the installed KiCad build, which was replaced before the final audit. Geometry
preservation was verified byte-for-byte against the board at the start of this
session after removing only the two added color entries.

Close/reopen the PCB project so an already-open editor cannot overwrite the saved
settings. In **Board Setup → Design Rules**, inspect Constraints, Net Classes,
Pre-defined Sizes and Custom Rules. Route with netclass widths and DRC avoidance
active. The owner should then update the PCB from the schematic, resolve the
reported footprint/spacing/mask issues, route, fill zones, and run DRC again.
Inspect final Gerber copper/mask/paste/drills and JLC's assembly/CAM preview before
ordering. Installed rules substantially improve coverage, but do not certify an
unfinished PCB or replace JLC's final review.

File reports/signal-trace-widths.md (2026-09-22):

# MARV V2 signal trace widths

Reviewed 2026-09-21 against the saved schematic netlist and PCB pad connections.

## Installed recommendation

Use **0.15 mm (about 6 mil)** for the 55 explicitly assigned `Signal` nets below.
This is a board-specific engineering choice, not an RP2354B datasheet minimum.
Ordinary logic interconnects do not need 0.20 mm for current capacity. Their
length, edge rate, loading and return path still matter, especially for SD and
QSPI clocks. Keep those paths short over a continuous reference; this width
change is not a timing or signal-integrity qualification.

The project and managed DFM profile now contain the `Signal` class and exact net
assignments. Clearance remains **0.15 mm**, vias remain **0.60 / 0.30 mm**, and
the global track minimum remains **0.15 mm**. The width menu is now 0.15, 0.20,
0.50 and 1.00 mm, plus the netclass selector. Power and USB classes are unchanged.
The existing signal tracks have now also been resized: **511 segments across all
55 nets are 0.15 mm** (509 previously at 0.20 mm and two LED_DIN segments at
0.50 mm). Only track-width fields changed; paths, endpoints, layers, vias, pads,
zones, power/USB tracks and schematic files were preserved. A read-only DRC
reports zero unconnected items and 531 existing findings, down from 540.
Recovery copy: `.dfm-backups/signal-widths-bml1p_w8/MARV-V2.kicad_pcb`.

## Exact 0.15 mm net list

Every name in this table is an exact assignment, not a wildcard.

| Function | Nets |
| --- | --- |
| ICM SPI and interrupts | `ICM_SCK`, `ICM_MOSI`, `ICM_MISO`, `ICM_CS`, `ICM_INT1`, `ICM_INT2` |
| ADXL SPI and interrupts | `ADXL_SCK`, `ADXL_MOSI`, `ADXL_MISO`, `ADXL_CS`, `ADXL_INT1`, `ADXL_INT2` |
| Barometer I2C and interrupt | `BARO_SCL`, `BARO_SDA`, `BARO_INT` |
| External magnetometer I2C | `MAG_SCL`, `MAG_SDA` |
| UART and ESC telemetry | `GPS_RX`, `GPS_TX`, `ELRS_RX`, `ELRS_TX`, `ESC_TELEM`, `ESC_TELEM_RX` |
| Actuator control signals | `PWM1`, `PWM2`, `PWM3`, `PWM4`, `PWM5`, `PWM6`, `PWM7`, `PWM8` |
| Spare logic IO | `IO_GPIO44`, `IO_GPIO45`, `IO_GPIO46`, `IO_GPIO47` |
| SWD debug | `SWCLK`, `SWDIO` |
| microSD | `SD_CLK_MCU`, `SD_CLK`, `SD_CMD`, `SD_DAT0`, `SD_DAT1`, `SD_DAT2`, `SD_DAT3` |
| QSPI and boot select | `QSPI_SCLK`, `QSPI_SD0`, `QSPI_SD1`, `QSPI_SD2`, `QSPI_SD3`, `FLASH_CS1`, `QSPI_SS` |
| LED logic and buttons | `LED_DATA`, `LED_DIN`, `MCU_RUN`, `BOOT_BTN` |

PWM carries control signals only; no actuator supply current flows in these nets.
The spare IO recommendation assumes logic/sense use, not direct load power.
Pull-ups on data nets do not turn them into power-distribution nets. Both sides
of series resistors R54, R55 and R58 are included. The optional U24 QSPI interface
still needs timing review at its intended clock rate when populated.

## Nets kept out of the thinner class

| Group | Nets | Treatment |
| --- | --- | --- |
| Main power | `5V_IN`, `V5_SYS`, `V3V3_SYS`, `U7_SW` | Existing Power default, 1.00 mm |
| Local power and ground | `USB_VBUS`, `V3V3_ANA`, `DVDD`, `VREG_LX`, `VREG_AVDD`, `GND` | Existing LocalPower default, 0.50 mm |
| USB data | `USB_DP`, `USB_DM`, `USB_DP_RP`, `USB_DM_RP` (also reserved `_MCU` names) | Existing USB default, 0.30 mm width / 0.20 mm gap; verify actual impedance |
| Crystal | `XIN`, `XOUT`, `XTAL_DRV` | Keep Default 0.20 mm; separate oscillator layout review |
| Analog/sense | `VBAT`, `VBAT_SENSE`, `VBUS_SENSE`, `CURR_SENSE_RAW`, `CURR_SENSE` | Keep Default 0.20 mm; possible later thinning after noise/layout review |
| Other | `U7_BST`, `U7_EN`, `USB_CC1`, `USB_CC2`, `USB_LED_A` | Keep Default 0.20 mm; outside this digital-signal change |

Defaults in this table are not measurements of existing copper. Existing power
branches include 0.20, 0.30 and 0.50 mm widths and were preserved. A short 0.30 mm
MCU supply branch is a different case from a shared supply trunk: assess current,
length, voltage drop and decoupling together. The LX switching loop needs the
manufacturer's layout treatment regardless of its netclass width.

USB is data, but it is deliberately excluded from blanket thinning. Raspberry
Pi recommends approximately **90 ohm differential impedance** and an uninterrupted
ground reference. Its example geometry belongs to its example board, not this
four-layer stackup. The existing 0.30/0.20 setting is not verified impedance.
[Raspberry Pi hardware design guide, section 5.1](https://pip-assets.raspberrypi.com/categories/1214-rp2350/documents/RP-008280-DS-1-hardware-design-with-rp2350.pdf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)

## How much thinner is practical?

| Width | Recommendation for this board |
| --- | --- |
| 0.20 mm (~8 mil) | Conservative previous signal default |
| **0.15 mm (~6 mil)** | Installed signal default; already within project rules |
| 0.125 mm (~5 mil) | Possible candidate for specific tight escapes; would require a deliberate rule revision and layout review |
| 0.10 mm (~4 mil) | Fabrication-capable with the specified copper, but not the chosen general default |

JLC publishes a 0.09 mm minimum width/space for four-or-more-layer FR4 with
0.5/1 oz copper. That manufacturing floor does not establish electrical suitability
or require using it. These recommendations assume the saved 1 oz outer / 0.5 oz
inner copper; heavier copper has different limits.
[JLC copper-weight and trace/space table](https://jlcpcb.com/help/article/jlcpcb-copper-weight)

Going from 0.20 to 0.15 mm reduces copper width by **25%**. At unchanged 0.15 mm
clearance, parallel-track center pitch falls from 0.35 to 0.30 mm: approximately
**14% less pitch**, not 25% less routing area. Ten parallel tracks occupy 3.35 mm
versus 2.85 mm between their outside edges, saving 0.50 mm. Vias and pad escapes
may still set the bottleneck; their sizes and clearances have not changed.

## Using the defaults in KiCad

Open the project again and use **netclass width** while routing. Disable automatic
inheritance of the starting track width if continuing an existing 0.20 mm segment
causes the router to keep that width.

Netclass width is a routing default, not a hard maximum and not an automatic
conversion of existing tracks. The owner subsequently requested conversion,
and the 511 existing signal segments have now been changed explicitly. A wider signal segment is not inherently a DRC
error. The owner can use **Edit Track & Via Properties** filtered to the `Signal`
netclass to change existing signal tracks to 0.15 mm, with only tracks selected
and vias excluded. Inspect the result and run DRC after changing copper. Avoid
an unfiltered board-wide width change because power and USB must keep their own
geometry. That track-only conversion has now been performed at the owner's explicit request; it did not move or reroute anything.
[KiCad PCB Editor documentation](https://docs.kicad.org/10.0/en/pcbnew/pcbnew.html)

The managed settings source is `config/dfm/jlcpcb.json`; `python3 tools/dfm.py
--check` verifies agreement with the project. A future profile application will
retain these signal assignments.

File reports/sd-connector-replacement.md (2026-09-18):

# J11 locking microSD replacement

J11 now selects Molex 47219-2001 (472192001), LCSC C164170: hinged metal lid,
closed and slid into the locked position. The change is schematic/library/BOM
only; a subsequent 3D update changes just J11's PCB model node, retaining
all PCB pads, nets and placement.

- [Manufacturer datasheet](../datasheets/472192001.pdf), 3 pages, generated
  2025-04-07; retrieved from https://www.es.co.th/Schemetic/PDF/472192001.PDF.
- [Manufacturer mechanical drawing](../datasheets/472192001-drawing.pdf),
  SD-47219-001 Rev. G, 1 page; retrieved from
  https://cdn.promelec.ru/upload/items/2020/09/01/472192001_sd.pdf.
- [Molex locking sequence and part listing](https://www.content.molex.com/dxdam/literature/987651-8263.pdf).

The local footprint is copied from KiCad 10.0.6's
`Connector_Card:microSD_HC_Molex_47219-2001`, retaining its geometry and
numbering. The drawing's recommended pattern was checked: eight 0.8 × 1.5 mm
contact pads on 1.1 mm pitch, four 1.45 × 2.0 mm shield/mounting pads,
13.75 mm between side mounting-pad centers and 8.30 mm between rows.
All four mounting pads use SH and connect to GND. The KiCad footprint is
rotated 180 degrees relative to the drawing's land-pattern view.

Card pins remain 1 DAT2, 2 DAT3, 3 CMD, 4 VDD, 5 CLK, 6 VSS, 7 DAT0, 8 DAT1.
The PIO native four-bit SD bus stays on GPIO26–31 with all five 10k pull-ups,
R58 22 ohm clock damping and C64/C65 decoupling retained.

This connector has no card-detect switch. The schematic removes R41 and
SD_DET, and marks U20 GPIO35 unconnected. GPIO34/35/37 are now unexposed
spares. All other electrical connections are preserved.

Validation: zero ERC violations; 48-GPIO and exact bus-net checks pass; all
107 components have assigned, resolved footprints with matching symbol pads.
The footprint/model audit now reports all 107 components OK. An exact-part
LCSC/EasyEDA STEP model was retrieved and attached; see the model provenance
record for source and alignment. The old connector model is no longer displayed.

PCB handoff: update J11 to the new footprint and remove R41. It is not a
land-pattern-compatible substitution. Provide clearance and access to lift
and slide the lid. The owner retains control of placement and routing.

Inspect the current model in KiCad's 3D viewer. The PCB
footprint pads still require the owner's update from the schematic.

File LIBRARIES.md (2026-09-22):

# Component and footprint references

Open `MARV-V2.kicad_pro` in KiCad. Project library tables reference local sensor
symbols, footprints and 3D models. Standard KiCad libraries are also required.
The schematic and [DESIGN_SPEC.md](DESIGN_SPEC.md) define the current circuit.

| Area | Where it lives |
| --- | --- |
| Sensor symbols | `MARV_Sensors.kicad_sym`: ICM-45686, BMP581, ADXL375 |
| MCU / regulators / discretes | Standard KiCad symbols; actual part numbers in schematic values |
| Project footprints | `MARV_Packages.pretty/` |
| Local STEP models | `MARV_Packages.3dshapes/` |
| Model provenance and licenses | [PROVENANCE.md](MARV_Packages.3dshapes/PROVENANCE.md) |
| Manufacturer PDFs | [datasheet index](datasheets/README.md) |
| Selected assembly parts | Schematic `LCSC` fields, exported by Fabrication Toolkit to `production/bom.csv` |

## Footprints that need project-specific attention

- U20: RP2354B QFN-80 plus exposed pad; local footprint/model.
- U21/U22/U23: project sensor LGAs. Their STEP bodies are stand-ins; use the
  manufacturer drawings to verify land patterns, orientation and pin 1.
- U7: standard TSOT-23-6 for AP63203; no TPS62913 footprint in the active design.
- L2: local `L_Changjiang_FTC404030S`, 4.7 uH in the current schematic.
- D20: `LED_WS2812B-2020_PLCC4_2.0x2.0mm` footprint and the **2020** symbol pinout
  for WS2812C-2020. The plain 5050 WS2812B symbol has a different pin order.
- J3: local 1x9 solder-pad row; assumed 2.00 mm pitch needs a physical ESC check.
- J10: local 1x3 SWD solder-pad row.
- J6/J7/J8: three local 1x14, 2.54 mm headers with trimmed courtyard/silkscreen.
- J4: local USB-C footprint/model; verify the manufacturer drawing for mechanical fit.
- J11: local Molex 47219-2001 (LCSC C164170) locking hinged-lid microSD footprint.
  Copied from KiCad 10 `Connector_Card:microSD_HC_Molex_47219-2001`; pads 1–8
  and four grounded SH tabs. No card-detect contacts. The exact-part LCSC/EasyEDA STEP model is stored locally and aligned with
  the replacement footprint. See `MARV_Packages.3dshapes/PROVENANCE.md`.
  All 107 schematic components now pass the footprint/model audit.
- H1–H4 and TP1–TP10: board features; no 3D body required.
- U24: unpopulated backside SOIC-8, **150 mil** expansion land. Documented fit options
  are W25Q32JVSNIQ flash or APS6404L-SQN-SN PSRAM; verify the exact package suffix
  before populating. C62 and R35 remain fitted on the front.

The retired power-symbol library and unused TPS2121/TPS62913/FTC303020D assets
were removed. The old 104031 SD footprint and model remain because the saved PCB
still uses that footprint; remove them after the owner transfers J11 to 47219.

## Checks and unresolved sourcing detail

```sh
python3 tools/audit_footprints.py build/checks/netlist.xml
```

This checks resolved files and pin/pad coverage, not package geometry or assembly
rotation. Inspect sensor pin 1, connector fit and JLC placement rotations before fabrication.

Existing sourcing choices retained when the duplicate CSV map was retired:

- C8/C65: C96446, 10 uF / 25 V X5R, while descriptive values still say
  10 uF / 10 V X7R.
- C7/C25/C59/C62: C52923, 1 uF / 25 V X5R, while descriptive values still say
  1 uF / 10 V X7R.
- Optional U24 fit choices remain W25Q32JVSNIQ C5355146 or APS6404L-SQN-SN
  C5360304 (150 mil SOIC/SOP-8); fit only one. U24 is currently DNP.
- Owner-soldered header sources: J6–J8 C2905490; J10 C49257.

No component was substituted during the plugin migration. Use schematic LCSC
fields for current selections, and JLC's ordering page for current stock/prices.

Previous library and placement revisions are available in Git history.

## BMP581 I2C schematic variant

`MARV_Sensors:BMP581_I2C` is a mode-specific copy of the existing BMP581 symbol,
with the same package and pad numbering. It names pins 2/4 as SCL/SDA and types
pin 5 (ADDR/SDO) as an input, matching its I2C address-strap role. The generic
BMP581 symbol remains available. CSB is tied to VDDIO and ADDR to GND in the
active schematic. This preserves ERC checking without waiving the address strap.

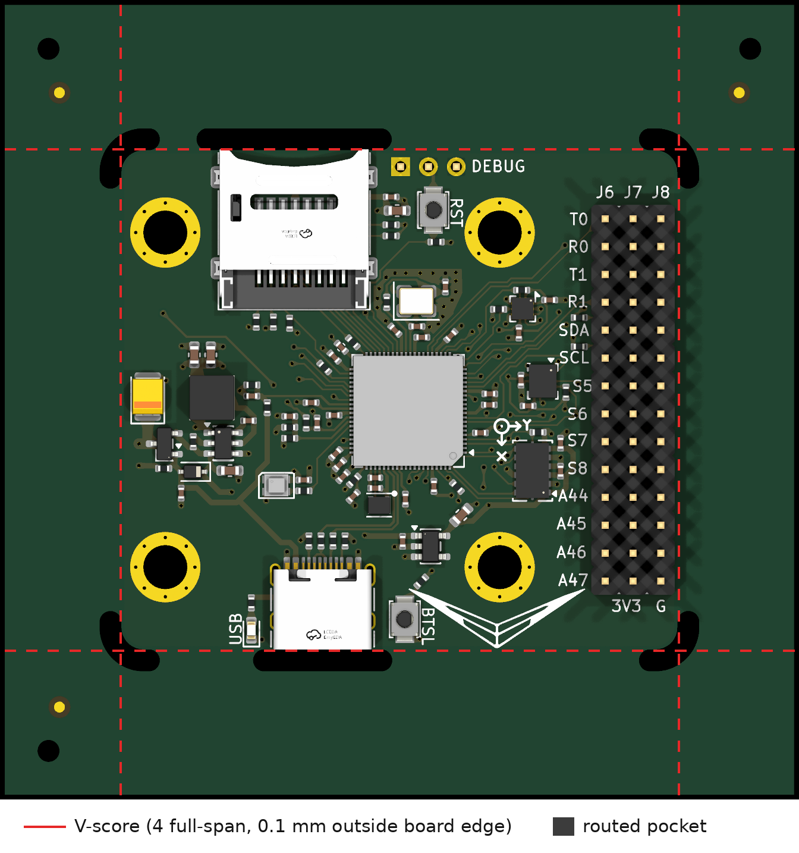
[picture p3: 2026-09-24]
images/pcb/marv-v2-panel-annotated.png

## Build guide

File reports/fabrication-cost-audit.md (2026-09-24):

# MARV V2 standard fabrication cost audit

Historical audit of the 2026-09-21 layout. The error counts below are retained
as history; see the [2026-09-23 manufacturing check](manufacturing-check.md) for
the current saved design and order files.

Reviewed 2026-09-21. The owner wants the budget spent on components rather than
precision PCB fabrication. The selected dimensions use ordinary four-layer
technology, but the current saved layout still has clearance violations and is
not ready for fabrication. The initial audit did not alter geometry. At the
owner's subsequent request, 511 existing signal segments were resized to
0.15 mm; their paths and every non-width PCB field were preserved.

## Keep these fabrication choices

| Feature | Required choice / saved state |
| --- | --- |
| Construction | Four-layer, 1.6 mm FR-4, existing standard 7628-style stackup |
| Copper | 1 oz outer, 0.5 oz inner; no heavy copper |
| Signals | 0.15 mm width, 0.15 mm minimum copper clearance |
| Vias | 0.60 mm diameter / 0.30 mm drill, ordinary through vias only |
| Via treatment | Ordinary mask treatment; no epoxy/resin fill or copper cap |
| Finish and mask | HASL with lead, green solder mask, as already selected |
| Special features | No requested blind/buried/microvias, backdrilling, gold fingers, edge plating, castellations or custom controlled-depth milling |
| Assembly | Front-side assembly; confirm Economic PCBA eligibility and actual component charges in the quote |

JLC explicitly describes 3.5 mil trace/space on four/six layers as available
without extra cost. Our 0.15 mm is about 5.9 mil, comfortably coarser.
[JLC standard routing guidance](https://jlcpcb.com/blog/complete-pcb-layout-guide)
Its copper table identifies 3 mil as an extra-cost option; this project does not
use it. [JLC copper and minimum feature table](https://jlcpcb.com/help/article/jlcpcb-copper-weight)

JLC's quote help identifies holes at least 0.30 mm with diameters at least
0.40 mm as having no small-via surcharge. This board uses 0.30/0.60, retaining
the owner's chosen 0.15 mm radial ring. Do not select the smaller-hole option
in the cart, even where another published combination is described as free:
the owner's previous quote added fees when selecting 0.20 mm holes.
[JLC quote help](https://cart.jlcpcb.com/quote/?fromDemo=yes)

The order form, rather than KiCad, selects resin filling, inspection/test options,
delivery speed and other chargeable services. Ordinary solder-mask plugging is
not the same process as resin-filled, copper-capped via-in-pad. The saved board
has tenting enabled and filling/capping disabled. Match the standard via
mask treatment to the actual order without requesting a paid fill/cap process.

## Saved geometry checks

- **172 vias:** all through vias, all 0.60/0.30 mm.
- **1,007 track segments after conversion:** 511 at 0.15 mm, 226 at 0.20 mm,
  28 at 0.30 mm, 226 at 0.50 mm, and 16 at 1.00 mm.
- Smallest drilled pad hole: **0.30 mm**, in the mounting-hole footprints.
  No pad uses a smaller drill hidden inside a footprint.
- USB plated slots: **0.60 mm wide**, with lengths 1.20/1.70 mm. These are
  ordinary through slots, above the project's 0.50 mm plated-slot minimum.
- USB nonplated locating holes: **0.65 mm**. Header holes are 1.00 mm;
  the four main mounting holes are 4.00 mm.
- Managed settings check passes. After the requested track conversion, every
  PCB field except the 511 selected widths is unchanged. Schematics and custom
  rules are unchanged.

## Existing problems that must be resolved before ordering

The initial read-only KiCad DRC returned **460 errors and 80 warnings**.
After the requested signal-track conversion it returned **451 errors and 80
warnings**, with zero unconnected items. Copper-clearance findings decreased
from 363 to 354; other category counts were unchanged. The table below records
the initial audit:

| Finding | Count |
| --- | ---: |
| Copper clearance | 363 |
| Hole clearance | 14 |
| Solder-mask bridges | 5 |
| Courtyard spacing | 78 |
| Small MCU land review warnings | 80 |

There were zero reported unconnected items. This run did not check schematic
parity, refill zones or save the board. Of the 363 copper-clearance reports,
239 involve existing filled zones; the owner should refill after layout edits
and recheck. The other 124 reports involve non-zone copper. Counts can repeat
the same physical conflict on multiple layers and are not unique defect counts.

One concrete example is the `BARO_SCL` via at (104.991623, 101.770024) and
`ICM_MISO` via at (104.474729, 102.074694): their reported copper separation is
approximately **0.000002 mm**, effectively touching relative to manufacturing
tolerances. Reducing signal-track width cannot fix this via-to-via gap. The
owner must resolve such conflicts using ordinary clearances, rather than
specifying a precision fabrication process. Existing tracks and placements
were preserved as required by AGENTS.md.

The 80 MCU warnings concern the generic minimum-pad review rule versus the
RP2354B footprint's 0.20 mm-wide lands. Do not enlarge or replace those lands
merely to silence warnings. The existing 0.4 mm-pitch package and LGA sensors
still require assembly/CAM acceptance with the selected HASL finish. A fine-pitch
component does not by itself establish a PCB precision surcharge, nor does a
basic PCB process guarantee the cheapest assembly option.

The initial report is `build/dfm/fabrication-cost-audit-drc.json`; the report
after conversion is `build/dfm/signal-widths-applied-drc.json`. Zones were not
refilled in either run.

## What is not guaranteed by this audit

No Gerbers were submitted and no current order-specific quote was obtained.
Standard dimensions avoid the identified small-trace/small-drill triggers;
they cannot guarantee the total bill or acceptance of the present layout.
Confirm the final CAM files and itemized quote after routing cleanup.

There is also a cost condition independent of geometry: JLC's quote help says
that selecting its **Aerospace** product category for a four-layer board requires
FR4 Tg155 and a four-wire Kelvin test. Because this design is a rocket/drone
controller, confirm the applicable classification with JLC at ordering time;
do not assume that all such fees would be caused by a small drill. No category
was selected or changed by this audit.
[JLC product-type requirements](https://cart.jlcpcb.com/quote/?fromDemo=yes)

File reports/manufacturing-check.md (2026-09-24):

# Manufacturing export verification — 2026-09-23

This records the original, unpanelized export. The later
[customer-supplied assembly frame](manufacturing-panel.md) supersedes its ZIP
and order handoff; source-design checks below remain applicable.

The local `production/` package was regenerated from the saved design with
KiCad 10.0.6 and the installed Fabrication Toolkit. All three files are current:

| Upload | File |
| --- | --- |
| PCB fabrication | [archived MARV-V2.zip](../build/panel-check/unpanelized-MARV-V2.zip) |
| Assembly BOM | [bom.csv](../production/bom.csv) |
| Assembly placements | [positions.csv](../production/positions.csv) |

The BOM and placement files are byte-for-byte identical to the previous
package. All 15 archive members also match after removing creation timestamps.
The ZIP passes its integrity check and contains four copper layers, front/back
mask, silk and paste, Edge.Cuts, and separate PTH/NPTH drills and drill maps.
The old outputs were preserved under `build/manufacturing-check/previous-production-*`.
Use the three `production/` upload files together; older `build/fab/` and
`build/assembly/` outputs remain superseded.

## Verification

| Check | Result |
| --- | --- |
| ERC, all severities | 0 violations |
| DRC, all severities and schematic parity | 0 errors, 104 warnings, 0 unconnected, 0 parity issues |
| Power/GPIO netlist check | Pass: 193 critical pin mappings, all 48 GPIO assignments |
| Footprint/library audit | 108 of 108 components pass |
| Assembly reference sets | PCB selection, BOM and positions agree; no duplicate placement references |
| Part selection | Every exported LCSC number matches both PCB and schematic |
| Assembly totals | 88 top-side placements, 34 distinct LCSC parts, 84 BOM rows |
| Geometry | 50.8 × 45.6 mm, four copper layers, 1.6 mm board |
| Vias | 179 through vias, all 0.60 mm diameter / 0.30 mm drill |
| Design preservation | All 39 captured design/library/settings file hashes unchanged |

The saved zones were exported without refill. No routing, placement, copper,
schematics, exclusions or rule severities were changed. Automatic component
translations and DNP exclusion were enabled, matching the saved export options;
extra layers, V-cuts, alternate outlines and all-active-layer export were disabled.

Detailed results are in `build/manufacturing-check/`: `erc.json`, `drc.json`,
`netlist.xml`, `footprint-audit.md`, `export-verification.json` and
`source-sha256.json`. Local `production/order-manifest.json` records hashes and
verification results; `production/SHA256SUMS` covers the three upload files.
These generated directories remain Git-ignored as documented in the README.

## Findings retained for review

| DRC warning | Count | Scope |
| --- | ---: | --- |
| Small SMD land review | 80 | U20 MCU lands trigger the generic 0.25 mm minimum-pad review rule; retain the package footprint and review CAM/assembly acceptance |
| Silkscreen graphic stroke | 8 | Graphic strokes below the project's 0.15 mm review threshold |
| Silkscreen overlap/clearance | 7 | Labels and graphic/footprint silk |
| Silkscreen near board edge | 6 | G2 graphic and J10 header outline; may be clipped in fabrication |
| Missing courtyard | 3 | Graphic footprints G1, G2 and G3 |

These are warning-level findings, not a warning-free signoff. The project also
retains five ignored check types: footprint filter mismatch, footprint type
mismatch, library footprint mismatch, track not centered on via, and tuning
profile track geometries. There are no individual excluded DRC markers.

`tools/dfm.py --check` reports project-setting drift. Comparing the parsed
settings shows only an additional **0.30 mm track-width preset** in the saved
project; applying the profile would remove it. Fabrication constraints are
unchanged. The owner's preset was preserved, and the profile was not applied.

## Order handoff

Keep the choices already specified in [README Ordering](../README.md#ordering):
5 PCBs, 2 assembled on the top side, 1 design, Single PCB, four layers, 1.6 mm,
green mask, white silk, HASL with lead, standard copper and 0.30 mm minimum via
holes. J6–J8/J10 remain owner-soldered, and U24 remains DNP.

Before paying, inspect the rendered board and assembly previews, especially
custom sensor rotations and L20's orientation dot toward pad 2 / DVDD. Confirm
the physical ESC pad pitch, current parts availability and quote, and CAM
acceptance of the fine-pitch lands with the selected finish. This local check
did not submit files to JLCPCB or validate its preview or inventory.

This report supersedes older reports' manufacturing-readiness counts for this
saved design. Re-run checks and regenerate the package after any design edit.

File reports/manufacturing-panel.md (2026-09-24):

# Customer-supplied V-cut frame — 2026-09-23

The saved [MARV-V2-panel.kicad_pcb](../MARV-V2-panel.kicad_pcb) is a
**72 × 72 mm, one-board manufacturing frame** for Standard assembly. The board
is held by **four full-span V-scores, one along each straight edge**. Only the
rounded corners and the USB-C/microSD overhangs are routed. There are no side
slots, no mouse-bite holes, and no added panel silkscreen. The original MARV-V2
circuit board and schematic are unchanged.

Panel preview

KiCad's 3D render does not model V-score grooves. See the
[mechanical cut drawing](../images/pcb/marv-v2-panel-vcuts.svg) for their locations.
The four `V-CUT` labels are fabrication annotations, not printed silkscreen.

## Upload this package

| JLCPCB step | File |
| --- | --- |
| PCB fabrication | [production/MARV-V2-panel.zip](../production/MARV-V2-panel.zip) |
| Assembly parts | [production/bom.csv](../production/bom.csv) |
| Assembly placement | [production/positions.csv](../production/positions.csv) |

Select **Standard**, **Top Side**, **Edge Rails/Fiducials: Added by Customer**.
The panel contains one circuit design and one finished board. Keep the intended
quantity of 5 boards/frames manufactured, 2 assembled. BOM and position CSVs are
byte-for-byte unchanged; component coordinates and origin are unchanged.
Tooling holes and fiducials are excluded from both assembly CSVs.

Re-upload the ZIP: this version replaces the earlier two-score/slot package.
Confirm JLC's CAM preview shows four straight V-scores and the routed corner
and connector pockets. The ZIP no longer includes the drill-map drawings
(reference only), whose overlapping legends cluttered JLC's viewer.

## Mechanical details

- Frame: 72 × 72 mm, centered at (100, 100) mm (JLC's V-cut / Standard
  assembly minimum is 70 × 70 mm).
- Original board body: 50.7 × 45.5 mm between Edge.Cuts centerlines.
- V-score centerlines: **x = 74.55 and 125.45 mm, y = 77.15 and 122.85 mm**,
  each spanning the full panel. Each is **0.10 mm outside** the original edge,
  so the finished board is 50.9 × 45.7 mm with a 0.10 mm lip on each side.
- The offset exists because the inner-plane pours stop 0.30 mm from the board
  edge; 0.10 mm puts the scores at JLC's 0.40 mm copper clearance without
  touching the copper.
- Routed pockets (2 mm cutter): one at each R2 corner, one under the microSD
  overhang (top) and one under the USB-C overhang (bottom). No other routing
  touches the board.
- Three 2 mm NPTH tooling holes remain. Three top-side fiducials sit at
  (69, 72), (131, 72) and (69, 128) mm, clear of all score lines.
- `User.1` contains only the four score lines and four `V-CUT` labels.
  Fabrication Toolkit merges this layer into the outline Gerber using its
  V-cut option.

Depanel by bending each rail along its score **away from the components**
(top and bottom rails especially, where the connectors overhang the pockets).

## Verification

- Copper-to-score clearance, all four copper layers (tracks, pads, copper
  graphics, filled zones): minimum **0.4005 mm** (V3V3_SYS pour, PWR layer)
  against JLC's 0.40 mm. Axis-aligned full-span scores make the bounding-box
  extreme the exact distance.
- Panel DRC: **0 errors, 0 unconnected items**, 100 warnings. Same categories
  as the source board except `silk_edge_clearance` drops from 6 to 2, only
  because the straight edges are now score lines, which DRC does not treat as
  board edges. Silk position is unchanged.
- Source file unchanged (SHA-256 matches the manifest). The panel keeps every
  source item verbatim except the four straight Edge.Cuts segments. No zones
  were modified or refilled.
- Versus the previous export: PTH/NPTH drills, B.Cu, both inner planes, both
  paste layers, back silk and back mask are identical apart from metadata.
  F.Cu, F.Mask and F.Silkscreen differ only by the three fiducial flashes, and
  the IPC netlist only by the three fiducial positions.
- The exported outline Gerber contains all four full-span score lines.

Evidence: `build/flush-panel-check/make_vcut4.py` (panel generator) and
`build/flush-panel-check/drc.json`. The previous state is backed up in
`build/flush-panel-check/previous-*`. Review JLC's assembly preview,
particularly sensor rotations and L20 polarity, as before.

## Future exports

Open **MARV-V2-panel.kicad_pro**. Use the installed Fabrication Toolkit with
**User.1 V-cuts enabled**, automatic component translations and DNP exclusion
on, and automatic zone refill off. These options are saved in
`fabrication-toolkit-options.json`. V-cut export must remain enabled so the
score lines reach the fabrication files; annotations are not on silkscreen.
The toolkit always adds `*-drl_map.gbr` drawings. Remove them from the ZIP
before uploading.

The panel is a saved manufacturing copy, not a live link. After a circuit-board
edit, synchronize the copy, recheck copper-to-score clearance and DRC, then
regenerate the package before ordering. Do not export the unpanelized source
board when selecting customer-supplied rails.

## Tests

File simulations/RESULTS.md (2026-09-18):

# Input-power simulation results

Generated from the saved schematic by `python3 tools/simulate_power_input.py`.

External source 5 V / assumed 0.05 ohm; USB 5 V / assumed 0.35 ohm. Combined V5_SYS load 0.5 A; extra external 5 V load 0 A.

The external source represents either the 2S–6S buck or the 1S boost **at its 5 V output**. The source converter itself is not simulated. Loads start at 2 ms; source events at 8 ms.

| Case | Before (V) | Event min–max (V) | Final (V) | External / USB final (A) |
| --- | ---: | ---: | ---: | ---: |
| External 5 V only | 4.952 | 4.952–4.952 | 4.952 | 0.500 / 0.000 |
| USB only | 4.315 | 4.315–4.315 | 4.315 | 0.000 / 0.502 |
| Both connected | 4.352 | 4.352–4.352 | 4.352 | 0.065 / 0.437 |
| USB plugged in; external stays | 4.952 | 4.352–4.952 | 4.352 | 0.065 / 0.437 |
| USB unplugged; external stays | 4.352 | 4.269–4.940 | 4.946 | 0.500 / 0.000 |
| External unplugged; USB stays | 4.352 | 4.315–4.352 | 4.315 | 0.000 / 0.502 |
| External only; 0.1 A to chosen load | 4.990 | 4.952–4.990 | 4.952 | 0.500 / 0.000 |

Lowest measured voltage in the event windows: **4.269 V**. AP63203 specified input minimum: **3.8 V**; margin **0.469 V**. This checks input availability, not the actual 3.3 V outputs.

| Case | External 5V_IN min / final (V) | Peak reverse into USB node (mA) | Peak reverse toward external input (mA) | Q1 / D1 final loss (W) |
| --- | ---: | ---: | ---: | ---: |
| External 5 V only | 4.974 / 4.974 | 0.0053 | 0.0000 | 0.0112 / 0.0000 |
| USB only | 0.000 / 0.000 | 0.0000 | 0.0000 | 0.0000 / 0.2544 |
| Both connected | 4.997 / 4.997 | 0.0000 | 0.0000 | 0.0421 / 0.2151 |
| USB plugged in; external stays | 4.974 / 4.997 | 0.0053 | 0.0000 | 0.0421 / 0.2151 |
| USB unplugged; external stays | 4.973 / 4.974 | 0.0057 | 0.0000 | 0.0141 / 0.0000 |
| External unplugged; USB stays | 4.841 / 4.813 | 0.0000 | 0.0000 | 0.0001 / 0.2542 |
| External only; 0.1 A to chosen load | 4.974 / 4.974 | 0.0053 | 0.0000 | 0.0112 / 0.0000 |

Reverse-current peaks include connection transients; they are not USB compliance limits. Losses are electrical model estimates, not temperatures.

USB drives Q1’s gate. With USB present, do not assume the low-resistance BEC path wins: D1 and Q1’s body diode can share the load. Unplugging USB lets the Q1 channel turn on.

**Limits:** vendor Q1 model; fitted D1 forward curve; approximate white LED; nominal capacitors. No regulator control loops, source current limits, battery chemistry, charging, converter cutoff, USB negotiation, PCB parasitics, noise or thermal simulation. D1 leakage at temperature is not bounded. The default 0.5 A is an explicit input-load assumption, not a measured board budget.

Exact decks, waveforms, logs and exported netlist: `/tmp/marv-input-power-qkgsqbbq`.

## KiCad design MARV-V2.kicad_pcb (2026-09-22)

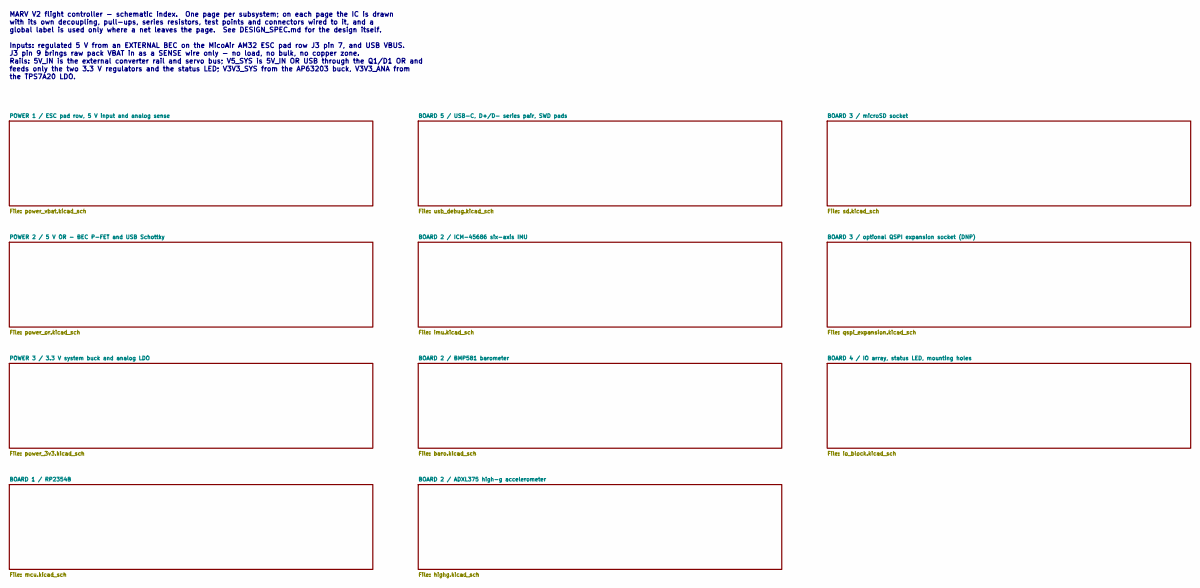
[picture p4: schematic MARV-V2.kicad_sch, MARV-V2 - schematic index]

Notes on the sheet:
MARV V2 flight controller - schematic index. One page per subsystem; on each page the IC is drawn with its own decoupling, pull-ups, series resistors, test points and connectors wired to it, and a global label is used only where a net leaves the page. See DESIGN_SPEC.md for the design itself. Input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

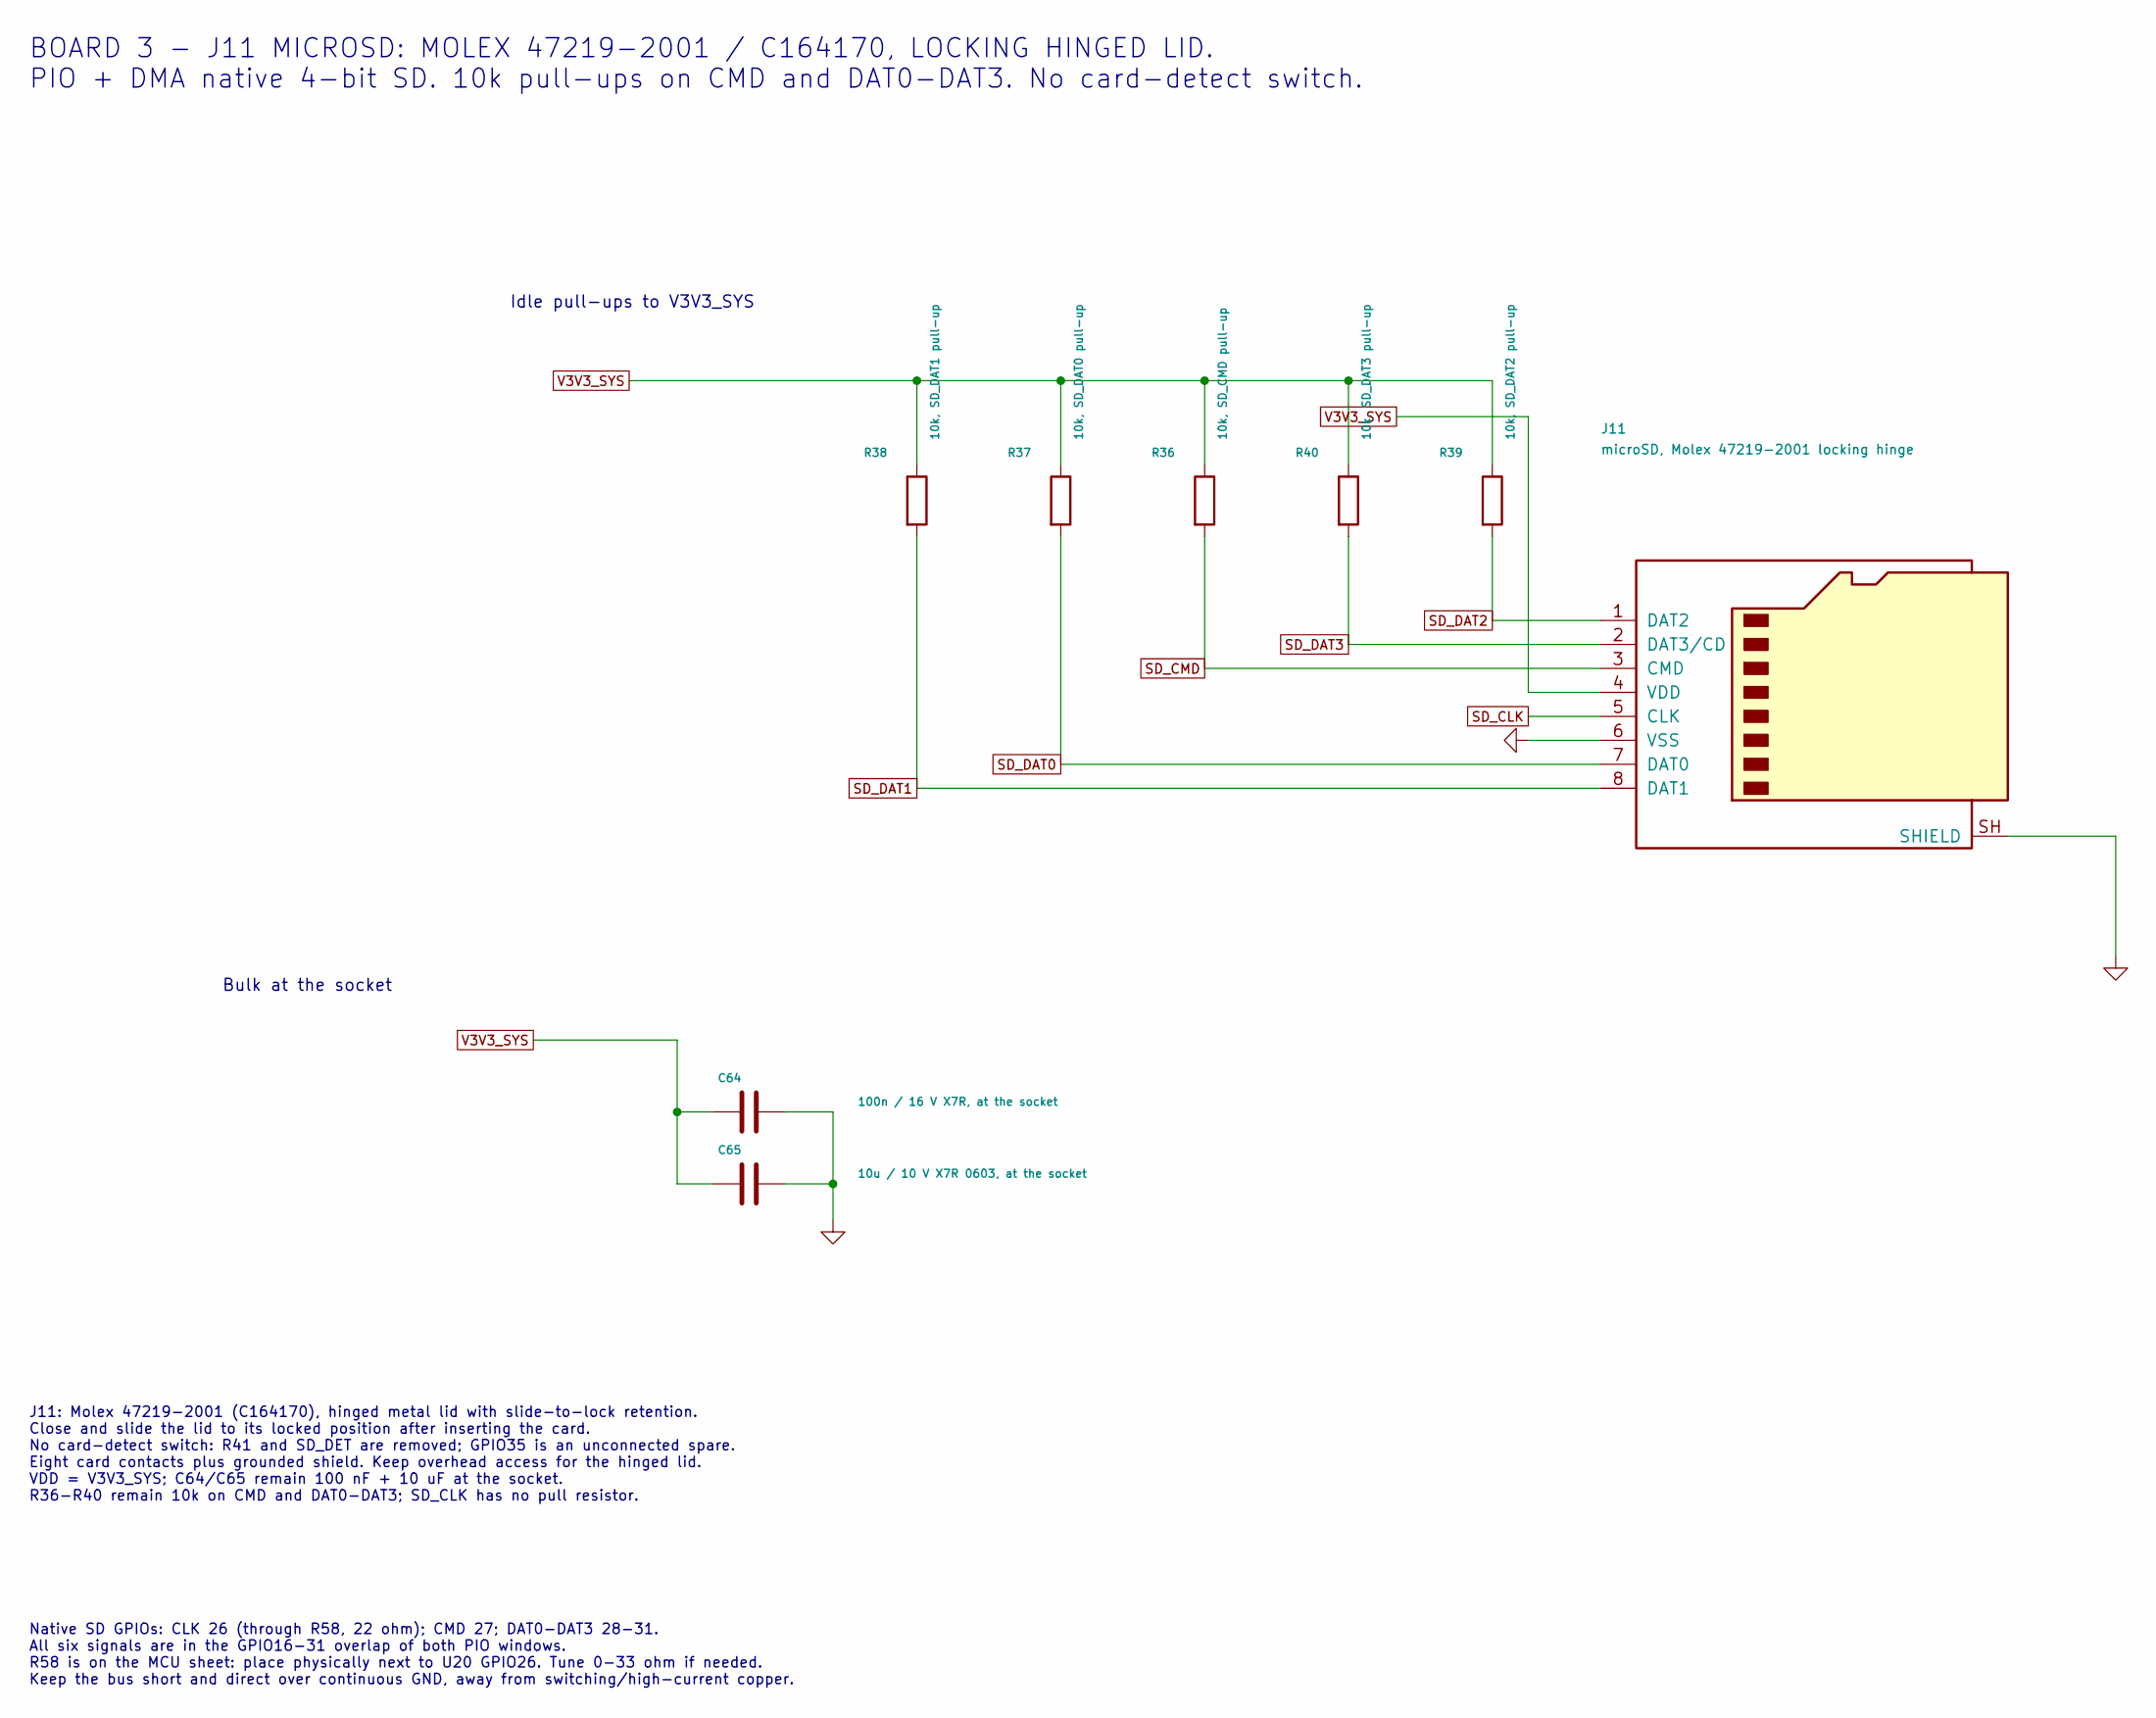
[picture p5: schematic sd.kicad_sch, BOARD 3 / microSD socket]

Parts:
C64: 100n / 16 V X7R, at the socket; C_0402_1005Metric; LCSC C1525
C65: 10u / 10 V X7R 0603, at the socket; C_0603_1608Metric; LCSC C96446
J11: microSD, Molex 47219-2001 locking hinge; microSD_HC_Molex_47219-2001; LCSC C164170
R36: 10k, SD_CMD pull-up; R_0402_1005Metric; LCSC C25744
R37: 10k, SD_DAT0 pull-up; R_0402_1005Metric; LCSC C25744
R38: 10k, SD_DAT1 pull-up; R_0402_1005Metric; LCSC C25744
R39: 10k, SD_DAT2 pull-up; R_0402_1005Metric; LCSC C25744
R40: 10k, SD_DAT3 pull-up; R_0402_1005Metric; LCSC C25744

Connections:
GND: C64.2, C65.2, J11.6 (VSS), J11.SH (SHIELD); also elsewhere on the board
SD_CLK: J11.5 (CLK); also elsewhere on the board
SD_CMD: J11.3 (CMD), R36.2; also elsewhere on the board
SD_DAT0: J11.7 (DAT0), R37.2; also elsewhere on the board
SD_DAT1: J11.8 (DAT1), R38.2; also elsewhere on the board
SD_DAT2: J11.1 (DAT2), R39.2; also elsewhere on the board
SD_DAT3: J11.2 (DAT3/CD), R40.2; also elsewhere on the board
V3V3_SYS: C64.1, C65.1, J11.4 (VDD), R36.1, R37.1, R38.1, R39.1, R40.1; also elsewhere on the board

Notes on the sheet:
J11: Molex 47219-2001 (C164170), hinged metal lid with slide-to-lock retention. Close and slide the lid to its locked position after inserting the card. No card-detect switch: R41 and SD_DET are removed; GPIO35 is an unconnected spare. Eight card contacts plus grounded shield. Keep overhead access 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
Idle pull-ups to V3V3_SYS
Native SD GPIOs: CLK 26 (through R58, 22 ohm); CMD 27; DAT0-DAT3 28-31. All six signals are in the GPIO16-31 overlap of both PIO windows. R58 is on the MCU sheet: place physically next to U20 GPIO26. Tune 0-33 ohm if needed. Keep the bus short and direct over continuous GND, away from switching/hig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
BOARD 3 - J11 MICROSD: MOLEX 47219-2001 / C164170, LOCKING HINGED LID. PIO + DMA native 4-bit SD. 10k pull-ups on CMD and DAT0-DAT3. No card-detect switch.
Bulk at the socket

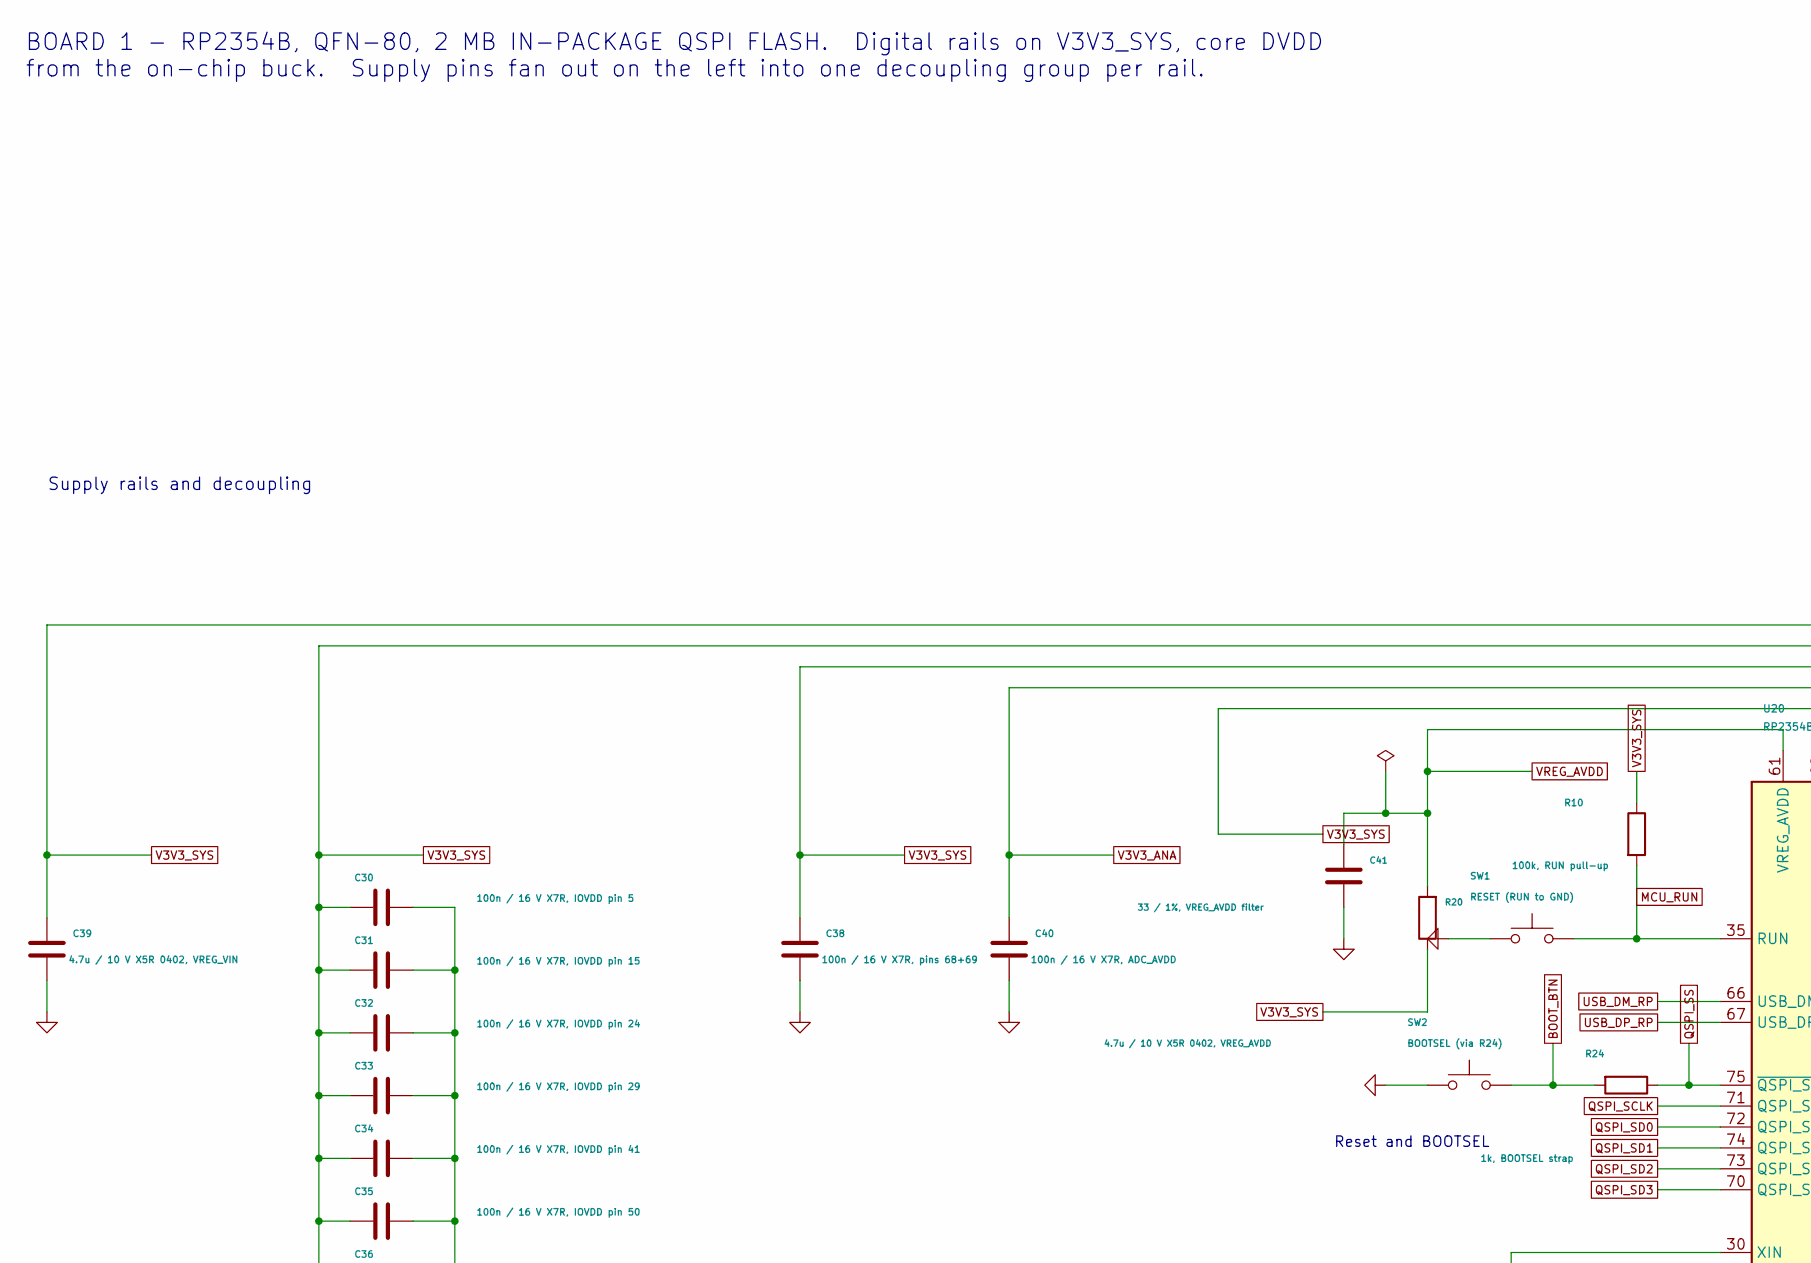
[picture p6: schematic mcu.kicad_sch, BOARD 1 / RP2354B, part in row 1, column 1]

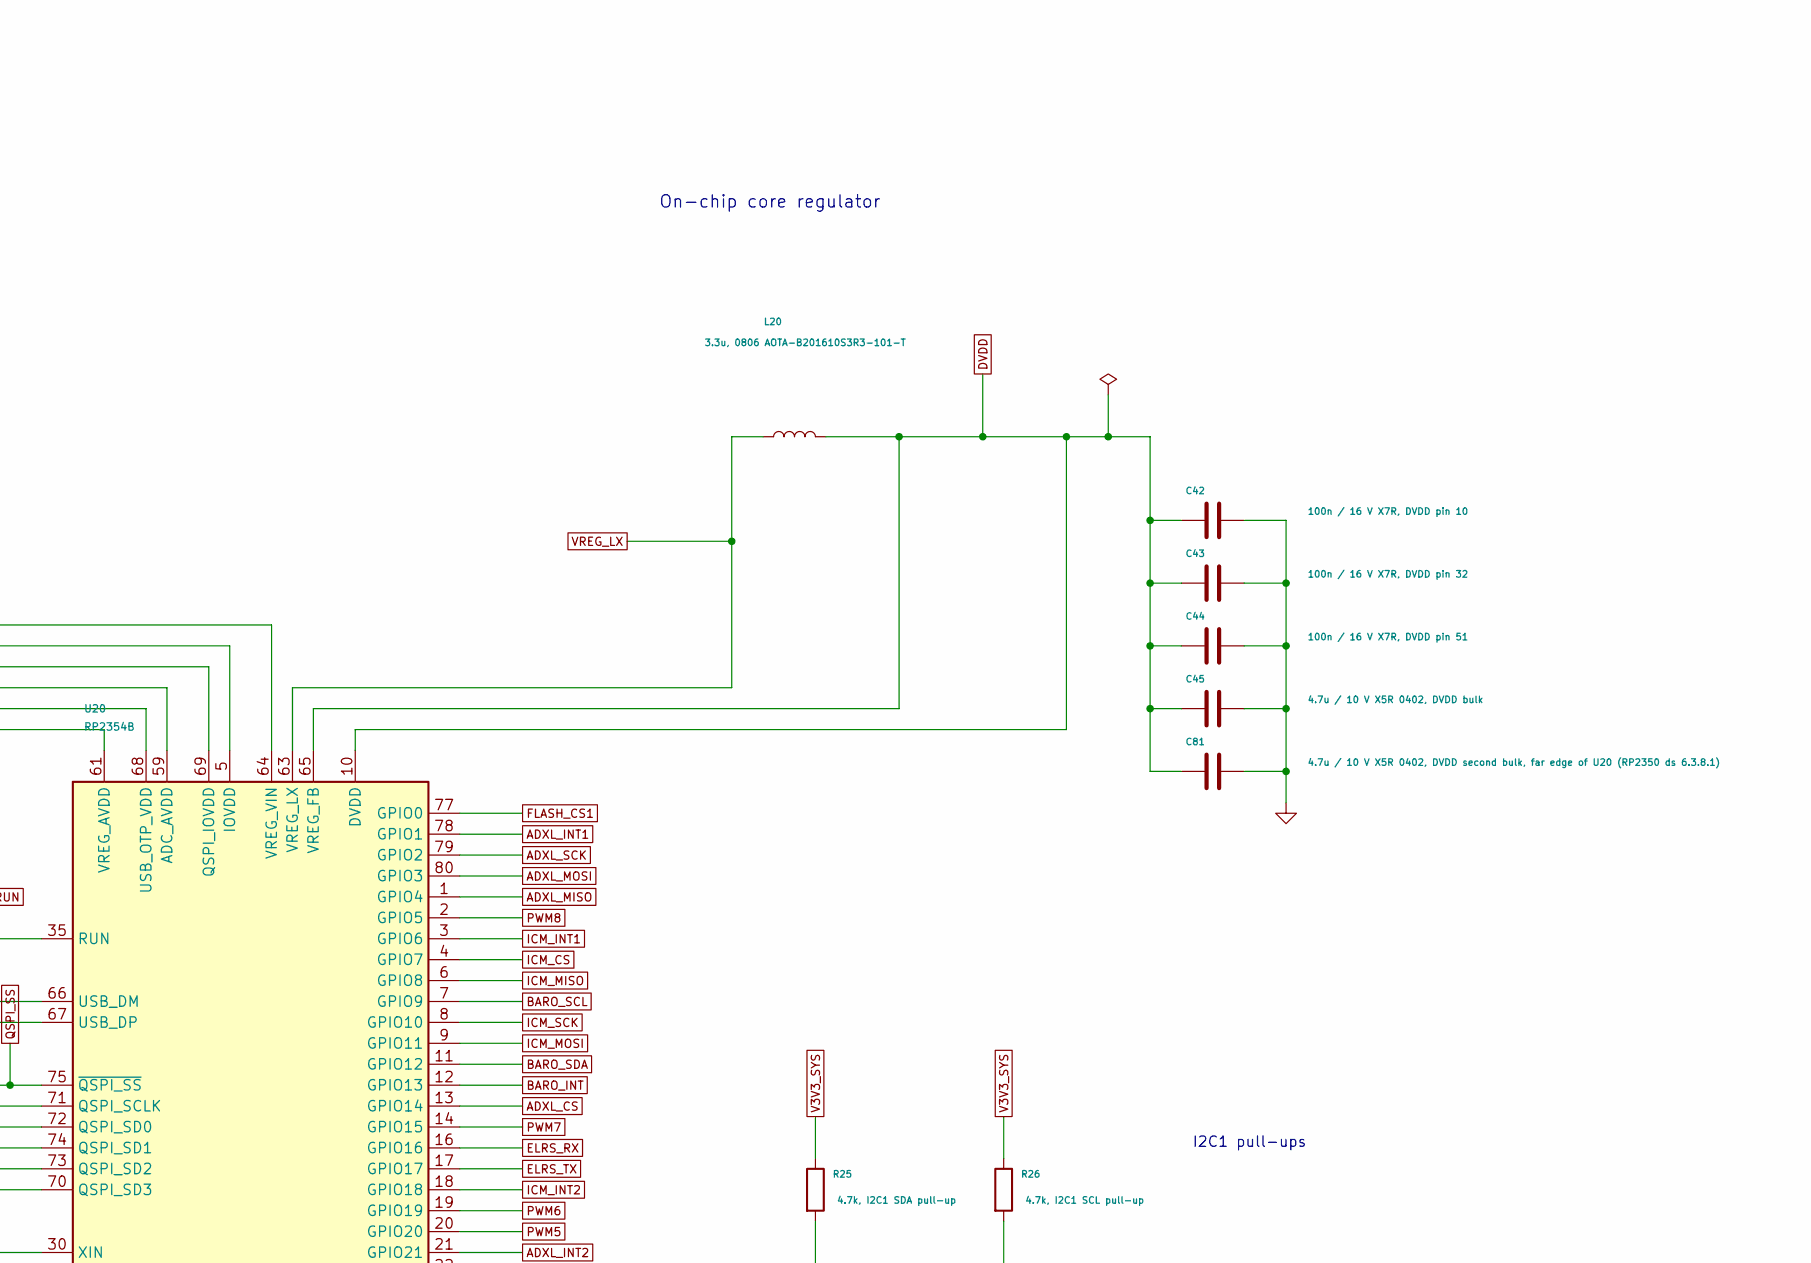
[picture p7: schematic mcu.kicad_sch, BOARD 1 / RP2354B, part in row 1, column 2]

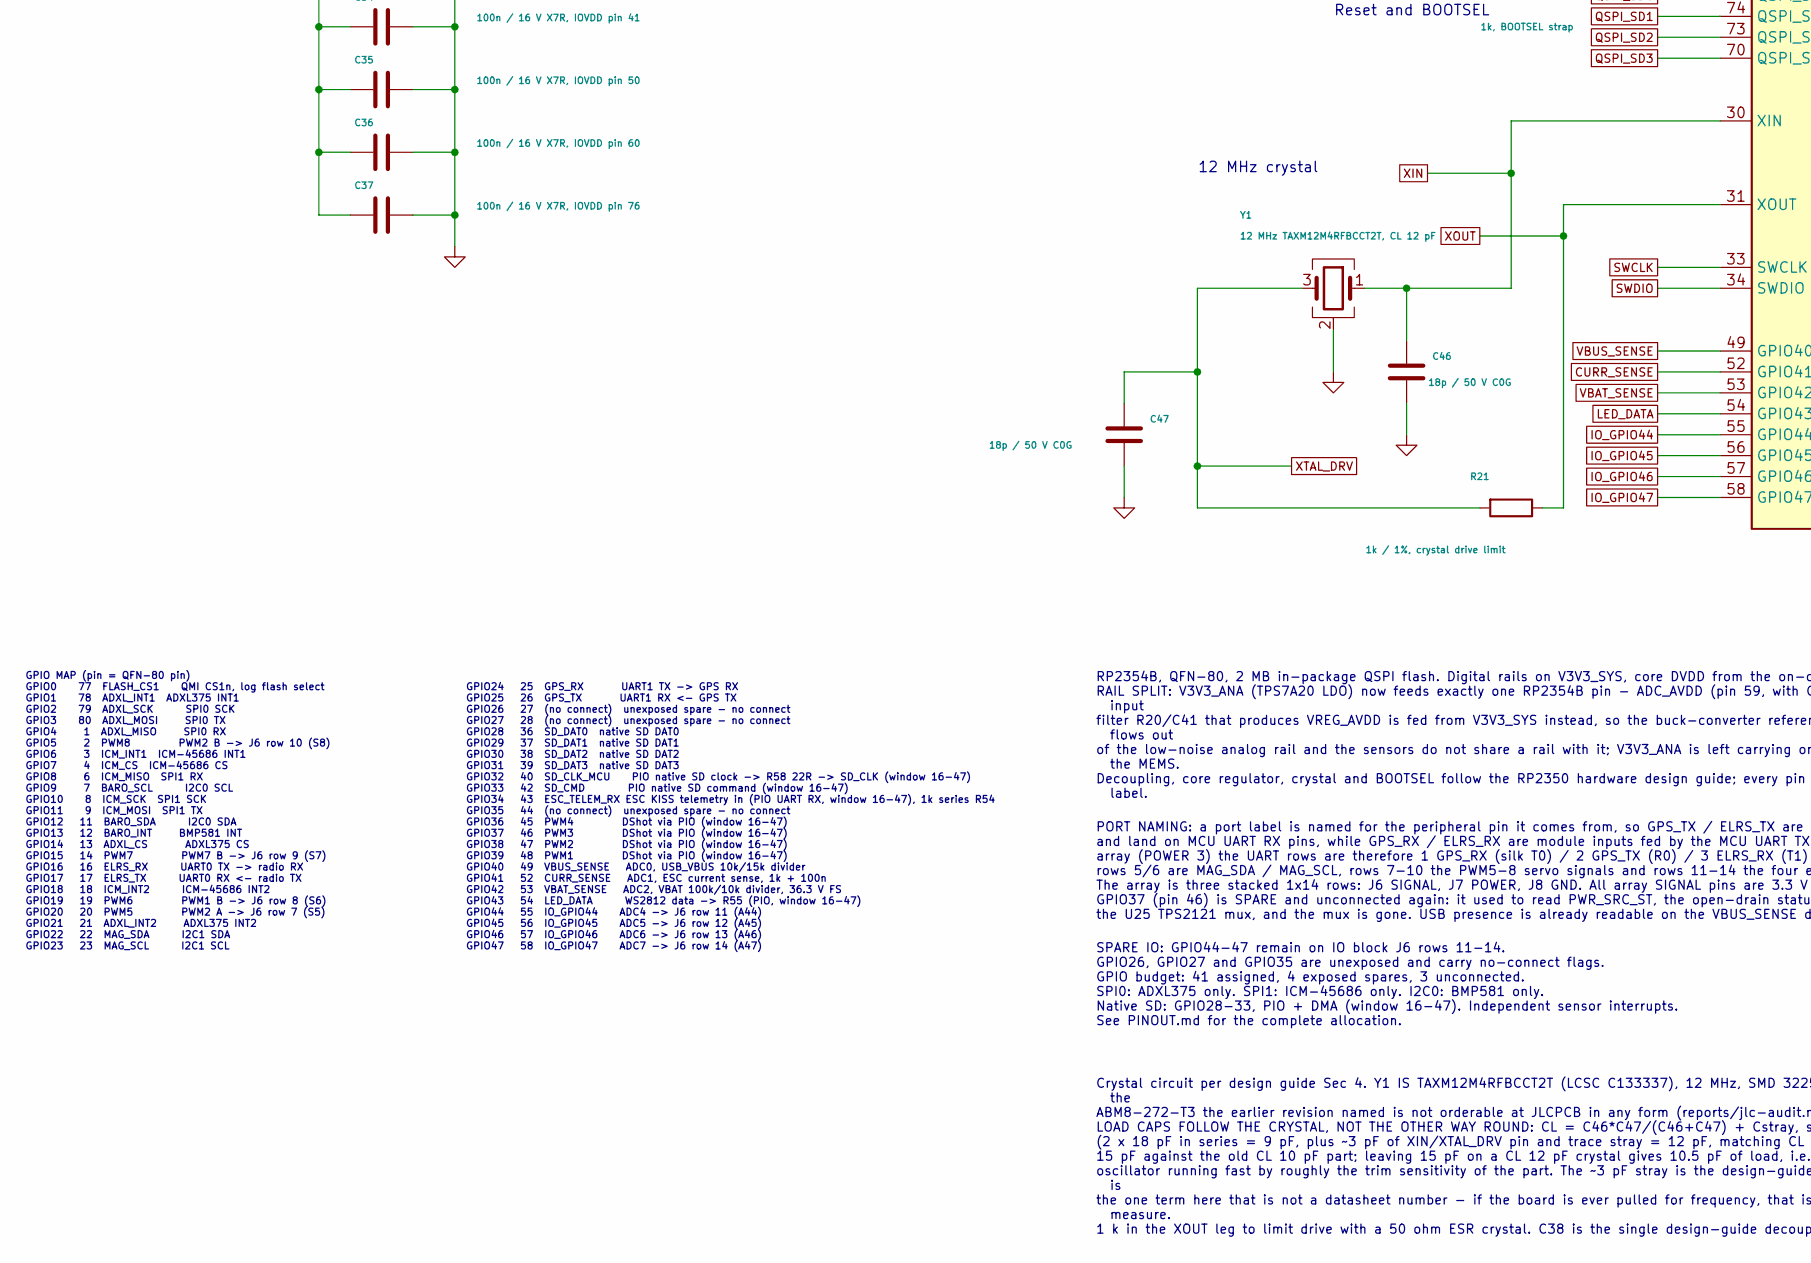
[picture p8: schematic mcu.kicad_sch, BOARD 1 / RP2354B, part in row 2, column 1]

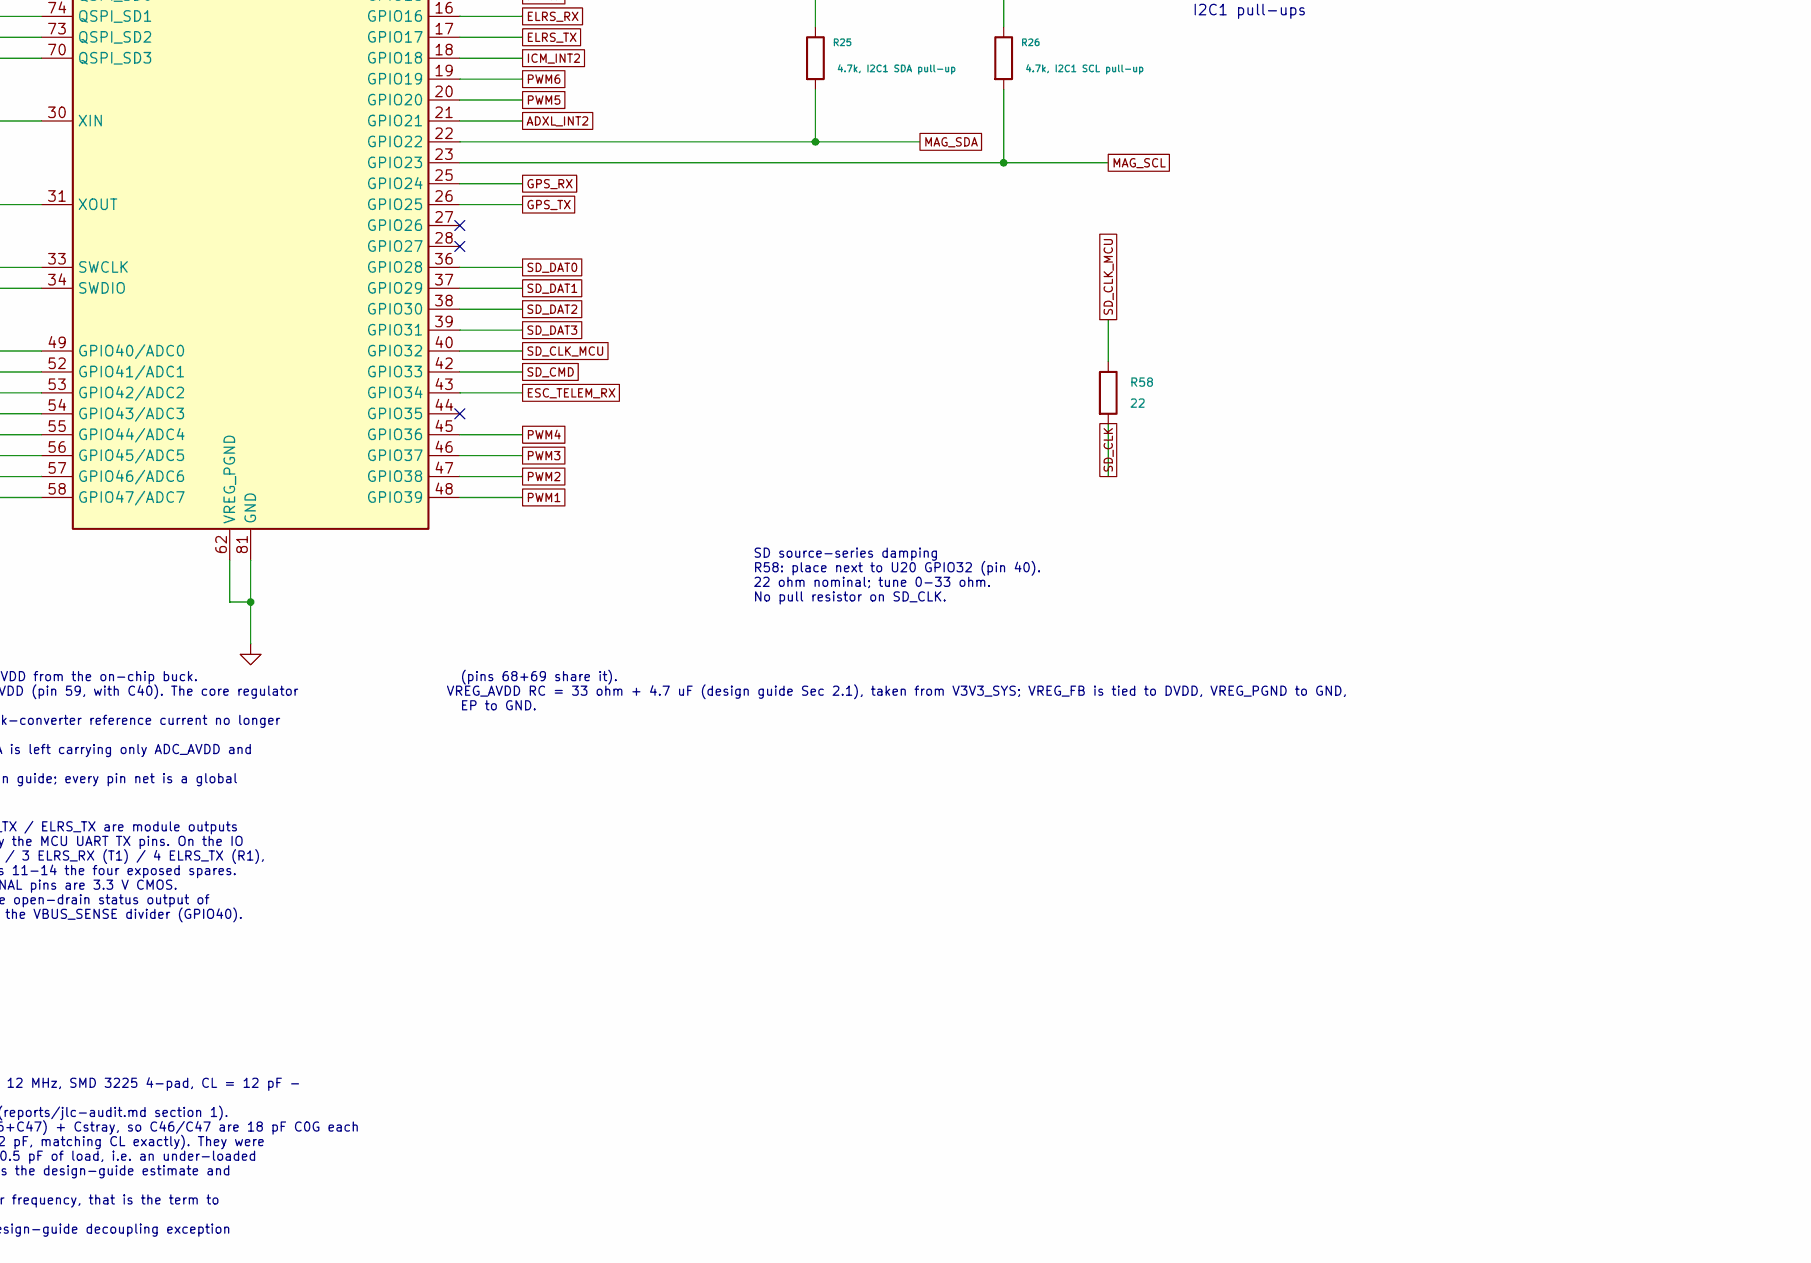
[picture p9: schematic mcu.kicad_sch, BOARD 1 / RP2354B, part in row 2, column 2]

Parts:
C30: 100n / 16 V X7R, IOVDD pin 5; C_0402_1005Metric; LCSC C1525
C31: 100n / 16 V X7R, IOVDD pin 15; C_0402_1005Metric; LCSC C1525
C32: 100n / 16 V X7R, IOVDD pin 24; C_0402_1005Metric; LCSC C1525
C33: 100n / 16 V X7R, IOVDD pin 29; C_0402_1005Metric; LCSC C1525
C34: 100n / 16 V X7R, IOVDD pin 41; C_0402_1005Metric; LCSC C1525
C35: 100n / 16 V X7R, IOVDD pin 50; C_0402_1005Metric; LCSC C1525
C36: 100n / 16 V X7R, IOVDD pin 60; C_0402_1005Metric; LCSC C1525
C37: 100n / 16 V X7R, IOVDD pin 76; C_0402_1005Metric; LCSC C1525
C38: 100n / 16 V X7R, pins 68+69; C_0402_1005Metric; LCSC C1525
C39: 4.7u / 10 V X5R 0402, VREG_VIN; C_0402_1005Metric; LCSC C23733
C40: 100n / 16 V X7R, ADC_AVDD; C_0402_1005Metric; LCSC C1525
C41: 4.7u / 10 V X5R 0402, VREG_AVDD; C_0402_1005Metric; LCSC C23733
C42: 100n / 16 V X7R, DVDD pin 10; C_0402_1005Metric; LCSC C1525
C43: 100n / 16 V X7R, DVDD pin 32; C_0402_1005Metric; LCSC C1525
C44: 100n / 16 V X7R, DVDD pin 51; C_0402_1005Metric; LCSC C1525
C45: 4.7u / 10 V X5R 0402, DVDD bulk; C_0402_1005Metric; LCSC C23733
C46, C47: 18p / 50 V C0G; C_0402_1005Metric; LCSC C541431
C81: 4.7u / 10 V X5R 0402, DVDD second bulk, far edge 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; C_0402_1005Metric; LCSC C23733
L20: 3.3u, 0806 AOTA-B201610S3R3-101-T; L_Murata_DFE201610P; LCSC C42411119
R10: 100k, RUN pull-up; R_0402_1005Metric; LCSC C25741
R20: 33 / 1%, VREG_AVDD filter; R_0402_1005Metric; LCSC C25105
R21: 1k / 1%, crystal drive limit; R_0402_1005Metric; LCSC C11702
R24: 1k, BOOTSEL strap; R_0402_1005Metric; LCSC C11702
R25: 4.7k, I2C1 SDA pull-up; R_0402_1005Metric; LCSC C25900
R26: 4.7k, I2C1 SCL pull-up; R_0402_1005Metric; LCSC C25900
R58: 22; R_0402_1005Metric; LCSC C25092
SW1: RESET (RUN to GND); SW_SPST_B3U-1000P; LCSC C231329
SW2: BOOTSEL (via R24); SW_SPST_B3U-1000P; LCSC C231329
U20: RP2354B; QFN-80-1EP_10x10mm_P0.4mm_EP3.4x3.4mm; LCSC C39843328
Y1: 12 MHz TAXM12M4RFBCCT2T, CL 12 pF; Crystal_SMD_3225-4Pin_3.2x2.5mm; LCSC C133337

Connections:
ADXL_CS: U20.13 (GPIO14); also elsewhere on the board
ADXL_INT1: U20.78 (GPIO1); also elsewhere on the board
ADXL_INT2: U20.21 (GPIO21); also elsewhere on the board
ADXL_MISO: U20.1 (GPIO4); also elsewhere on the board
ADXL_MOSI: U20.80 (GPIO3); also elsewhere on the board
ADXL_SCK: U20.79 (GPIO2); also elsewhere on the board
BARO_INT: U20.12 (GPIO13); also elsewhere on the board
BARO_SCL: U20.7 (GPIO9); also elsewhere on the board
BARO_SDA: U20.11 (GPIO12); also elsewhere on the board
BOOT_BTN: R24.2, SW2.1
CURR_SENSE: U20.52 (GPIO41/ADC1); also elsewhere on the board
DVDD: C42.1, C43.1, C44.1, C45.1, C81.1, L20.2, U20.10 (DVDD), U20.32 (DVDD), U20.51 (DVDD), U20.65 (VREG_FB)
ELRS_RX: U20.16 (GPIO16); also elsewhere on the board
ELRS_TX: U20.17 (GPIO17); also elsewhere on the board
ESC_TELEM_RX: U20.43 (GPIO34); also elsewhere on the board
FLASH_CS1: U20.77 (GPIO0); also elsewhere on the board
GND: C30.2, C31.2, C32.2, C33.2, C34.2, C35.2, C36.2, C37.2, C38.2, C39.2, C40.2, C41.2, C42.2, C43.2, C44.2, C45.2, C46.2, C47.2, C81.2, SW1.2, SW2.2, U20.62 (VREG_PGND), U20.81 (GND), Y1.2 (G), Y1.4 (G); also elsewhere on the board
GPS_RX: U20.25 (GPIO24); also elsewhere on the board
GPS_TX: U20.26 (GPIO25); also elsewhere on the board
ICM_CS: U20.4 (GPIO7); also elsewhere on the board
ICM_INT1: U20.3 (GPIO6); also elsewhere on the board
ICM_INT2: U20.18 (GPIO18); also elsewhere on the board
ICM_MISO: U20.6 (GPIO8); also elsewhere on the board
ICM_MOSI: U20.9 (GPIO11); also elsewhere on the board
ICM_SCK: U20.8 (GPIO10); also elsewhere on the board
IO_GPIO44: U20.55 (GPIO44/ADC4); also elsewhere on the board
IO_GPIO45: U20.56 (GPIO45/ADC5); also elsewhere on the board
IO_GPIO46: U20.57 (GPIO46/ADC6); also elsewhere on the board
IO_GPIO47: U20.58 (GPIO47/ADC7); also elsewhere on the board
LED_DATA: U20.54 (GPIO43/ADC3); also elsewhere on the board
MAG_SCL: R26.2, U20.23 (GPIO23); also elsewhere on the board
MAG_SDA: R25.2, U20.22 (GPIO22); also elsewhere on the board
MCU_RUN: R10.2, SW1.1, U20.35 (RUN)
PWM1: U20.48 (GPIO39); also elsewhere on the board
PWM2: U20.47 (GPIO38); also elsewhere on the board
PWM3: U20.46 (GPIO37); also elsewhere on the board
PWM4: U20.45 (GPIO36); also elsewhere on the board
PWM5: U20.20 (GPIO20); also elsewhere on the board
PWM6: U20.19 (GPIO19); also elsewhere on the board
PWM7: U20.14 (GPIO15); also elsewhere on the board
PWM8: U20.2 (GPIO5); also elsewhere on the board
QSPI_SCLK: U20.71 (QSPI_SCLK); also elsewhere on the board
QSPI_SD0: U20.72 (QSPI_SD0); also elsewhere on the board
QSPI_SD1: U20.74 (QSPI_SD1); also elsewhere on the board
QSPI_SD2: U20.73 (QSPI_SD2); also elsewhere on the board
QSPI_SD3: U20.70 (QSPI_SD3); also elsewhere on the board
QSPI_SS: R24.1, U20.75 (~QSPI_SS)
SD_CLK: R58.2; also elsewhere on the board
SD_CLK_MCU: R58.1, U20.40 (GPIO32)
SD_CMD: U20.42 (GPIO33); also elsewhere on the board
SD_DAT0: U20.36 (GPIO28); also elsewhere on the board
SD_DAT1: U20.37 (GPIO29); also elsewhere on the board
SD_DAT2: U20.38 (GPIO30); also elsewhere on the board
SD_DAT3: U20.39 (GPIO31); also elsewhere on the board
SWCLK: U20.33 (SWCLK); also elsewhere on the board
SWDIO: U20.34 (SWDIO); also elsewhere on the board
USB_DM_RP: U20.66 (USB_DM); also elsewhere on the board
USB_DP_RP: U20.67 (USB_DP); also elsewhere on the board
V3V3_ANA: C40.1, U20.59 (ADC_AVDD); also elsewhere on the board
V3V3_SYS: C30.1, C31.1, C32.1, C33.1, C34.1, C35.1, C36.1, C37.1, C38.1, C39.1, R10.1, R20.1, R25.1, R26.1, U20.5 (IOVDD), U20.15 (IOVDD), U20.24 (IOVDD), U20.29 (IOVDD), U20.41 (IOVDD), U20.50 (IOVDD), U20.60 (IOVDD), U20.64 (VREG_VIN), U20.68 (USB_OTP_VDD), U20.69 (QSPI_IOVDD), U20.76 (IOVDD); also elsewhere on the board
VBAT_SENSE: U20.53 (GPIO42/ADC2); also elsewhere on the board
VBUS_SENSE: U20.49 (GPIO40/ADC0); also elsewhere on the board
VREG_AVDD: C41.1, R20.2, U20.61 (VREG_AVDD)
VREG_LX: L20.1, U20.63 (VREG_LX)
XIN: C46.1, U20.30 (XIN), Y1.1
XOUT: R21.1, U20.31 (XOUT)
XTAL_DRV: C47.1, R21.2, Y1.3

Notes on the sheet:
On-chip core regulator
Supply rails and decoupling
GPIO MAP (pin = QFN-80 pin) GPIO0 77 FLASH_CS1 QMI CS1n, log flash select GPIO1 78 ADXL_INT1 ADXL375 INT1 GPIO2 79 ADXL_SCK SPI0 SCK GPIO3 80 ADXL_MOSI SPI0 TX GPIO4 1 ADXL_MISO SPI0 RX GPIO5 2 PWM8 PWM2 B -> J6 row 10 (S8) GPIO6 3 ICM_INT1 ICM-45686 INT1 GPIO7 4 ICM_CS ICM-45686 CS GPIO8 6 ICM_MIS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
PORT NAMING: a port label is named for the peripheral pin it comes from, so GPS_TX / ELRS_TX are module outputs and land on MCU UART RX pins, while GPS_RX / ELRS_RX are module inputs fed by the MCU UART TX pins. On the IO array (POWER 3) the UART rows are therefore 1 GPS_RX (silk T0) / 2 GPS_TX (R0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
I2C1 pull-ups
BOARD 1 - RP2354B, QFN-80, 2 MB IN-PACKAGE QSPI FLASH. Digital rails on V3V3_SYS, core DVDD from the on-chip buck. Supply pins fan out on the left into one decoupling group per rail.
SPARE IO: GPIO44-47 remain on IO block J6 rows 11-14. GPIO26, GPIO27 and GPIO35 are unexposed and carry no-connect flags. GPIO budget: 41 assigned, 4 exposed spares, 3 unconnected. SPI0: ADXL375 only. SPI1: ICM-45686 only. I2C0: BMP581 only. Native SD: GPIO28-33, PIO + DMA (window 16-47). Independe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
(pins 68+69 share it). VREG_AVDD RC = 33 ohm + 4.7 uF (design guide Sec 2.1), taken from V3V3_SYS; VREG_FB is tied to DVDD, VREG_PGND to GND, EP to GND.
SD source-series damping R58: place next to U20 GPIO32 (pin 40). 22 ohm nominal; tune 0-33 ohm. No pull resistor on SD_CLK.
Reset and BOOTSEL
12 MHz crystal
GPIO24 25 GPS_RX UART1 TX -> GPS RX GPIO25 26 GPS_TX UART1 RX <- GPS TX GPIO26 27 (no connect) unexposed spare - no connect GPIO27 28 (no connect) unexposed spare - no connect GPIO28 36 SD_DAT0 native SD DAT0 GPIO29 37 SD_DAT1 native SD DAT1 GPIO30 38 SD_DAT2 native SD DAT2 GPIO31 39 SD_DAT3 native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
RP2354B, QFN-80, 2 MB in-package QSPI flash. Digital rails on V3V3_SYS, core DVDD from the on-chip buck. RAIL SPLIT: V3V3_ANA (TPS7A20 LDO) now feeds exactly one RP2354B pin - ADC_AVDD (pin 59, with C40). The core regulator input filter R20/C41 that produces VREG_AVDD is fed from V3V3_SYS instead, 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
Crystal circuit per design guide Sec 4. Y1 IS TAXM12M4RFBCCT2T (LCSC C133337), 12 MHz, SMD 3225 4-pad, CL = 12 pF - the ABM8-272-T3 the earlier revision named is not orderable at JLCPCB in any form (reports/jlc-audit.md section 1). LOAD CAPS FOLLOW THE CRYSTAL, NOT THE OTHER WAY ROUND: CL = C46*C47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

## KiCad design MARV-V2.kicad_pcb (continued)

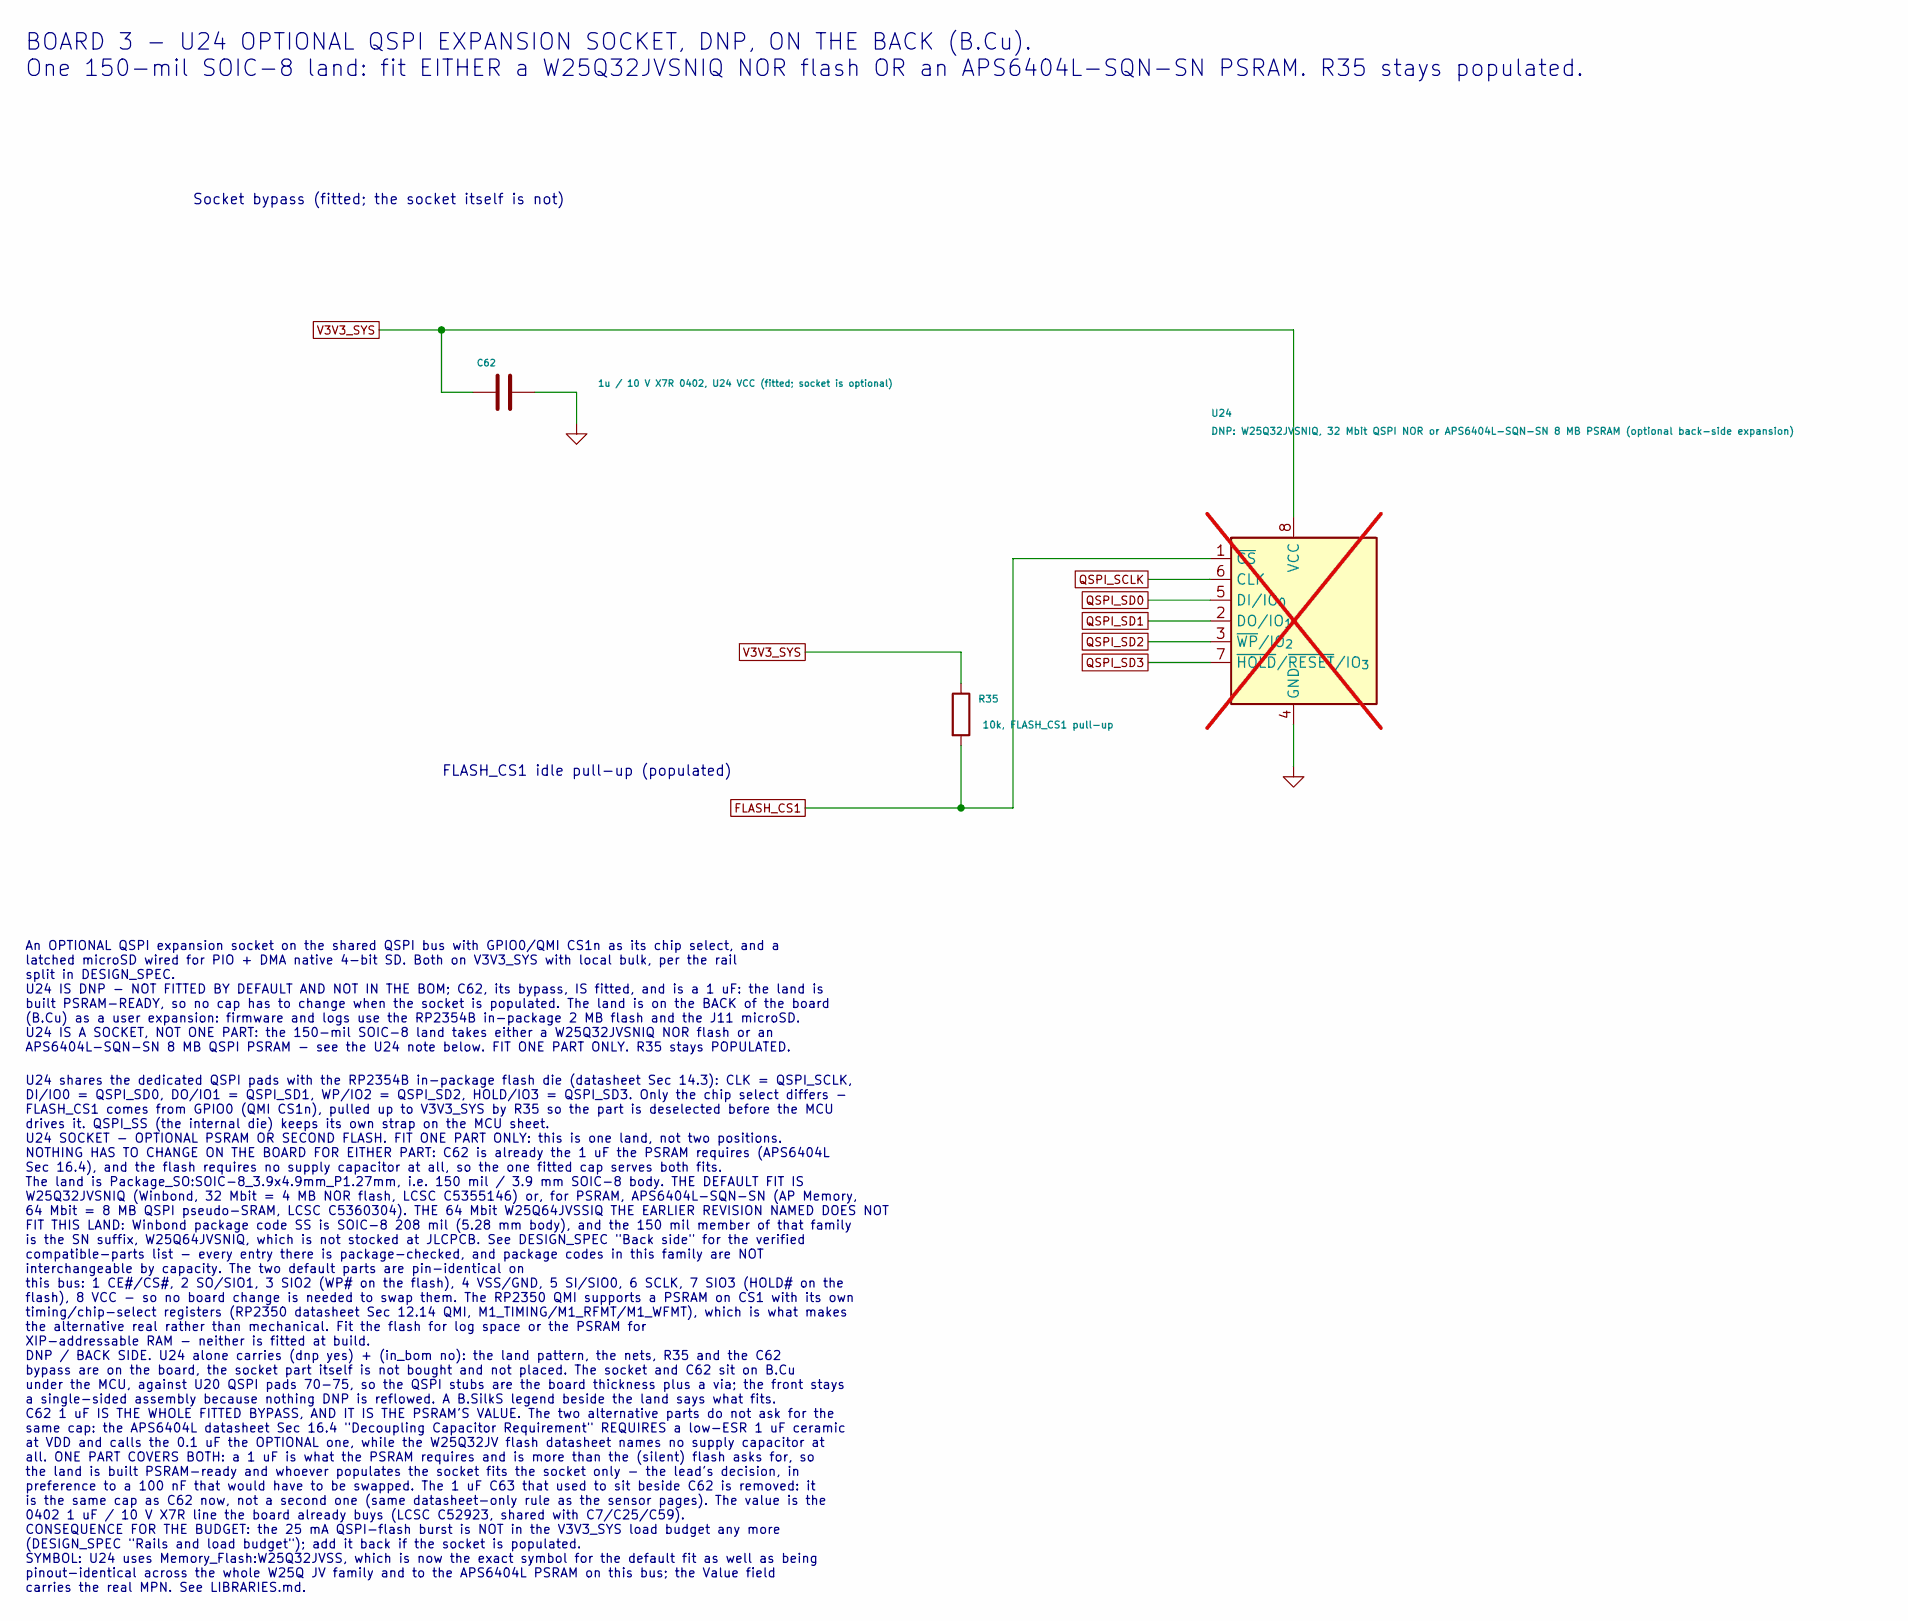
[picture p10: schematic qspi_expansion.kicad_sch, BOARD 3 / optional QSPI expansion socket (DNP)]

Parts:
C62: 1u / 10 V X7R 0402, U24 VCC (fitted; socket is op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; C_0402_1005Metric; LCSC C52923
R35: 10k, FLASH_CS1 pull-up; R_0402_1005Metric; LCSC C25744
U24: DNP: W25Q32JVSNIQ, 32 Mbit QSPI NOR or APS6404L-S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; SOIC-8_3.9x4.9mm_P1.27mm; not fitted

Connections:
FLASH_CS1: R35.2, U24.1 (~CS); also elsewhere on the board
GND: C62.2, U24.4 (GND); also elsewhere on the board
QSPI_SCLK: U24.6 (CLK); also elsewhere on the board
QSPI_SD0: U24.5 (DI/IO_{0}); also elsewhere on the board
QSPI_SD1: U24.2 (DO/IO_{1}); also elsewhere on the board
QSPI_SD2: U24.3 (~WP/IO_{2}); also elsewhere on the board
QSPI_SD3: U24.7 (~HOLD/~RESET/IO_{3}); also elsewhere on the board
V3V3_SYS: C62.1, R35.1, U24.8 (VCC); also elsewhere on the board

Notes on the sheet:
FLASH_CS1 idle pull-up (populated)
An OPTIONAL QSPI expansion socket on the shared QSPI bus with GPIO0/QMI CS1n as its chip select, and a latched microSD wired for PIO + DMA native 4-bit SD. Both on V3V3_SYS with local bulk, per the rail split in DESIGN_SPEC. U24 IS DNP - NOT FITTED BY DEFAULT AND NOT IN THE BOM; C62, its bypass, IS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
Socket bypass (fitted; the socket itself is not)
BOARD 3 - U24 OPTIONAL QSPI EXPANSION SOCKET, DNP, ON THE BACK (B.Cu). One 150-mil SOIC-8 land: fit EITHER a W25Q32JVSNIQ NOR flash OR an APS6404L-SQN-SN PSRAM. R35 stays populated.
U24 shares the dedicated QSPI pads with the RP2354B in-package flash die (datasheet Sec 14.3): CLK = QSPI_SCLK, DI/IO0 = QSPI_SD0, DO/IO1 = QSPI_SD1, WP/IO2 = QSPI_SD2, HOLD/IO3 = QSPI_SD3. Only the chip select differs - FLASH_CS1 comes from GPIO0 (QMI CS1n), pulled up to V3V3_SYS by R35 so the par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

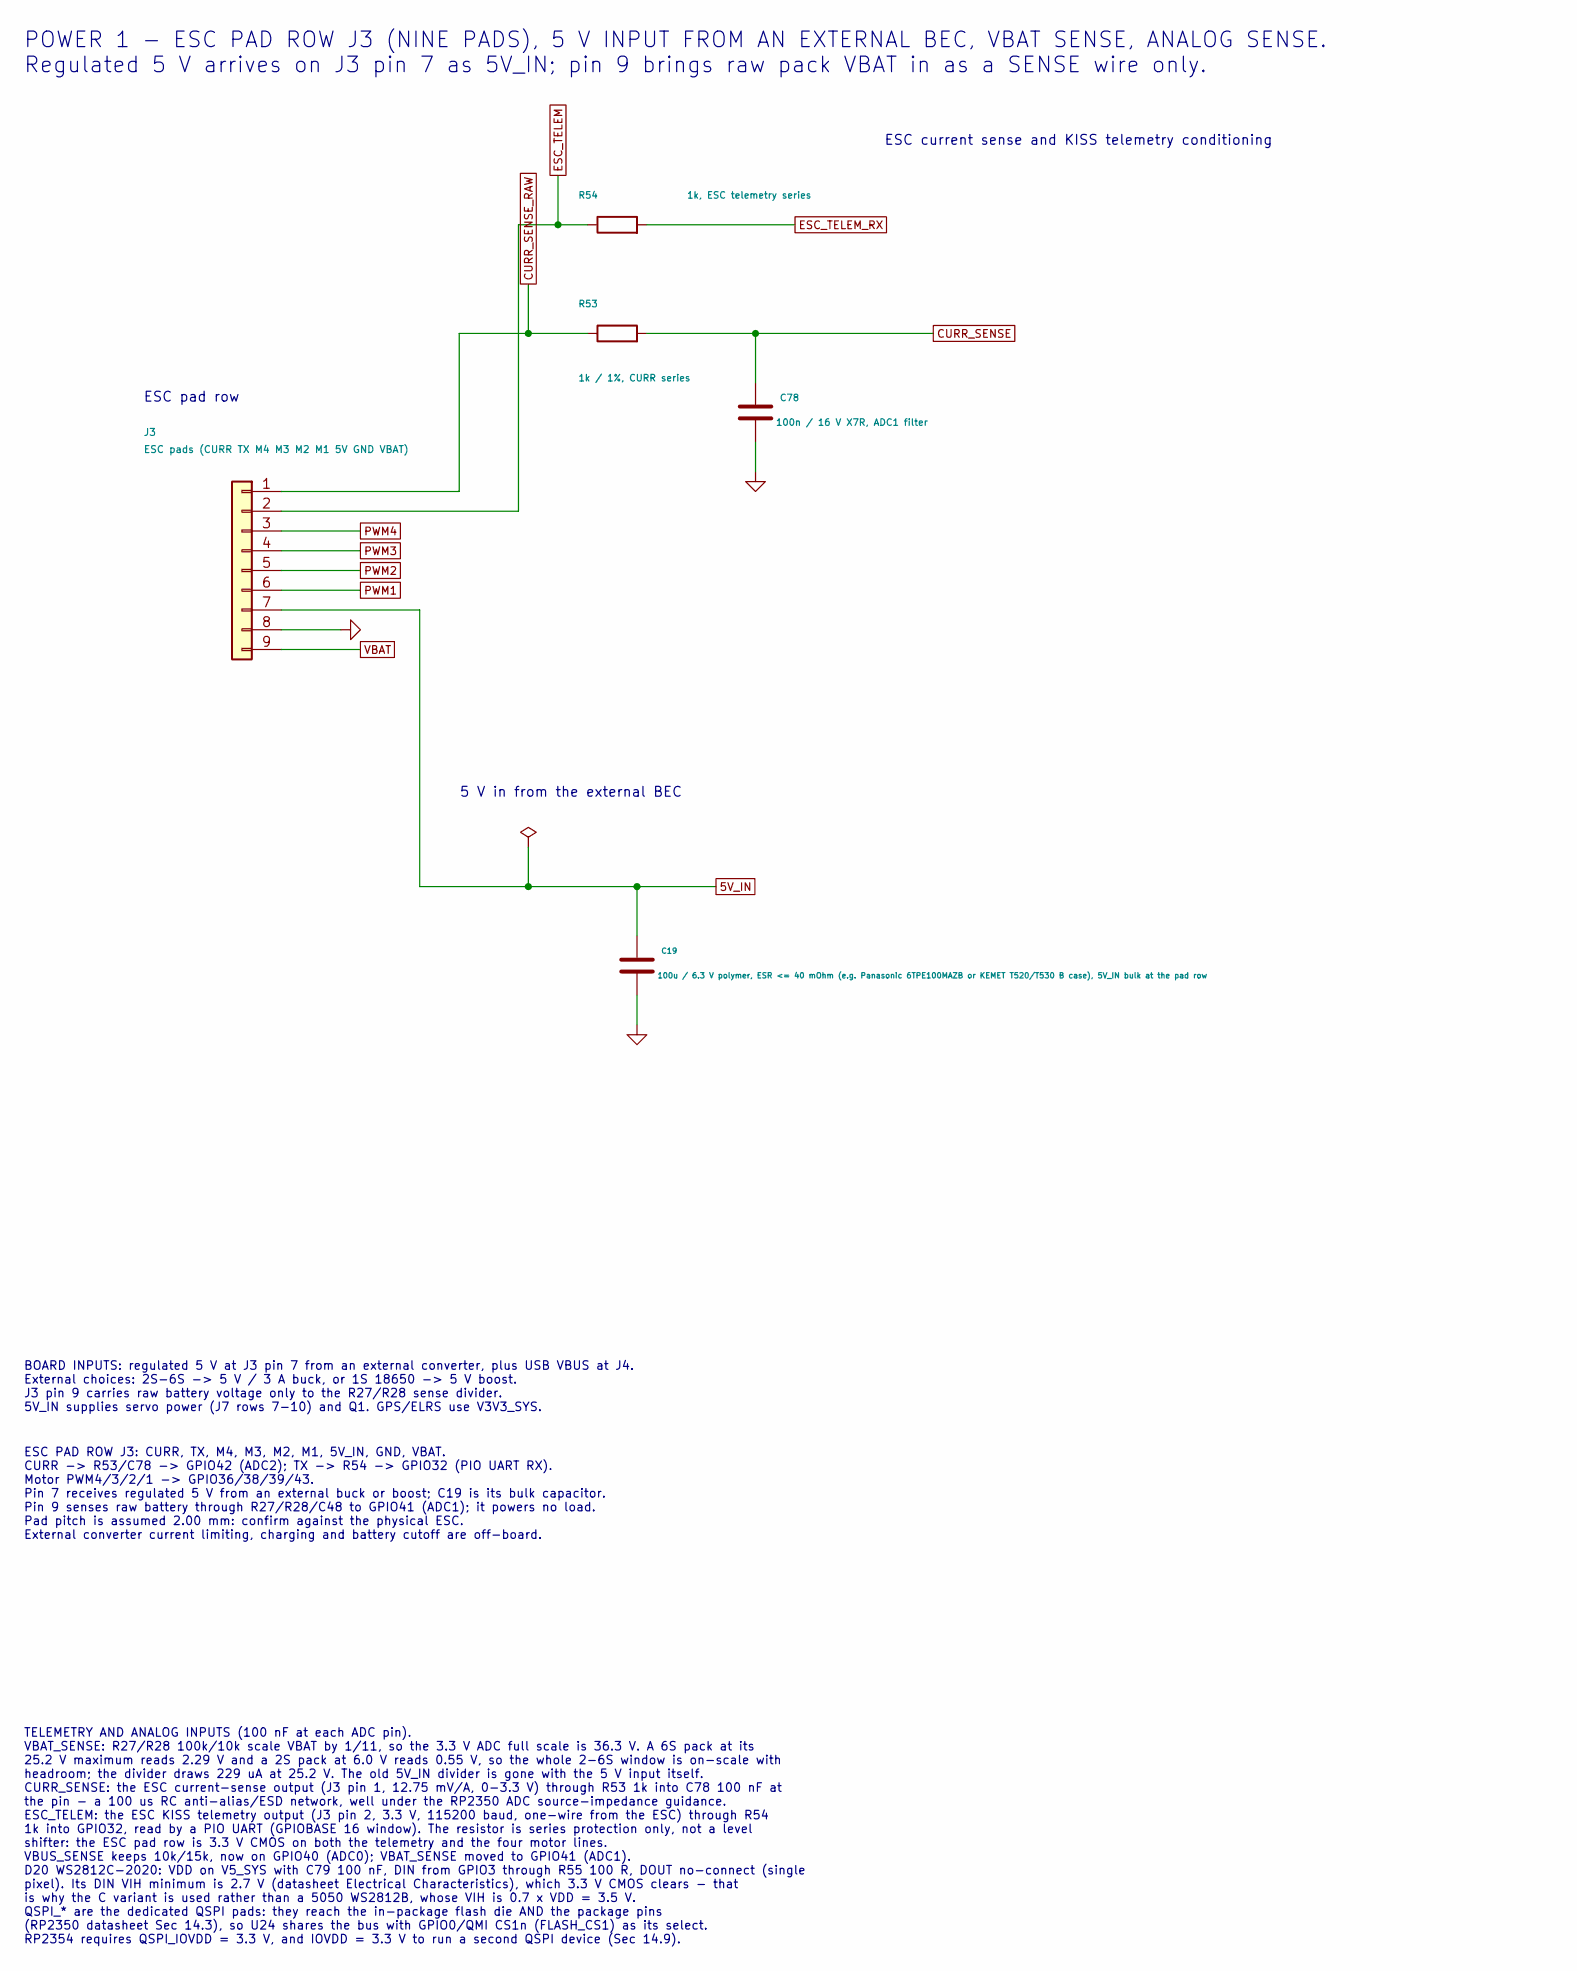
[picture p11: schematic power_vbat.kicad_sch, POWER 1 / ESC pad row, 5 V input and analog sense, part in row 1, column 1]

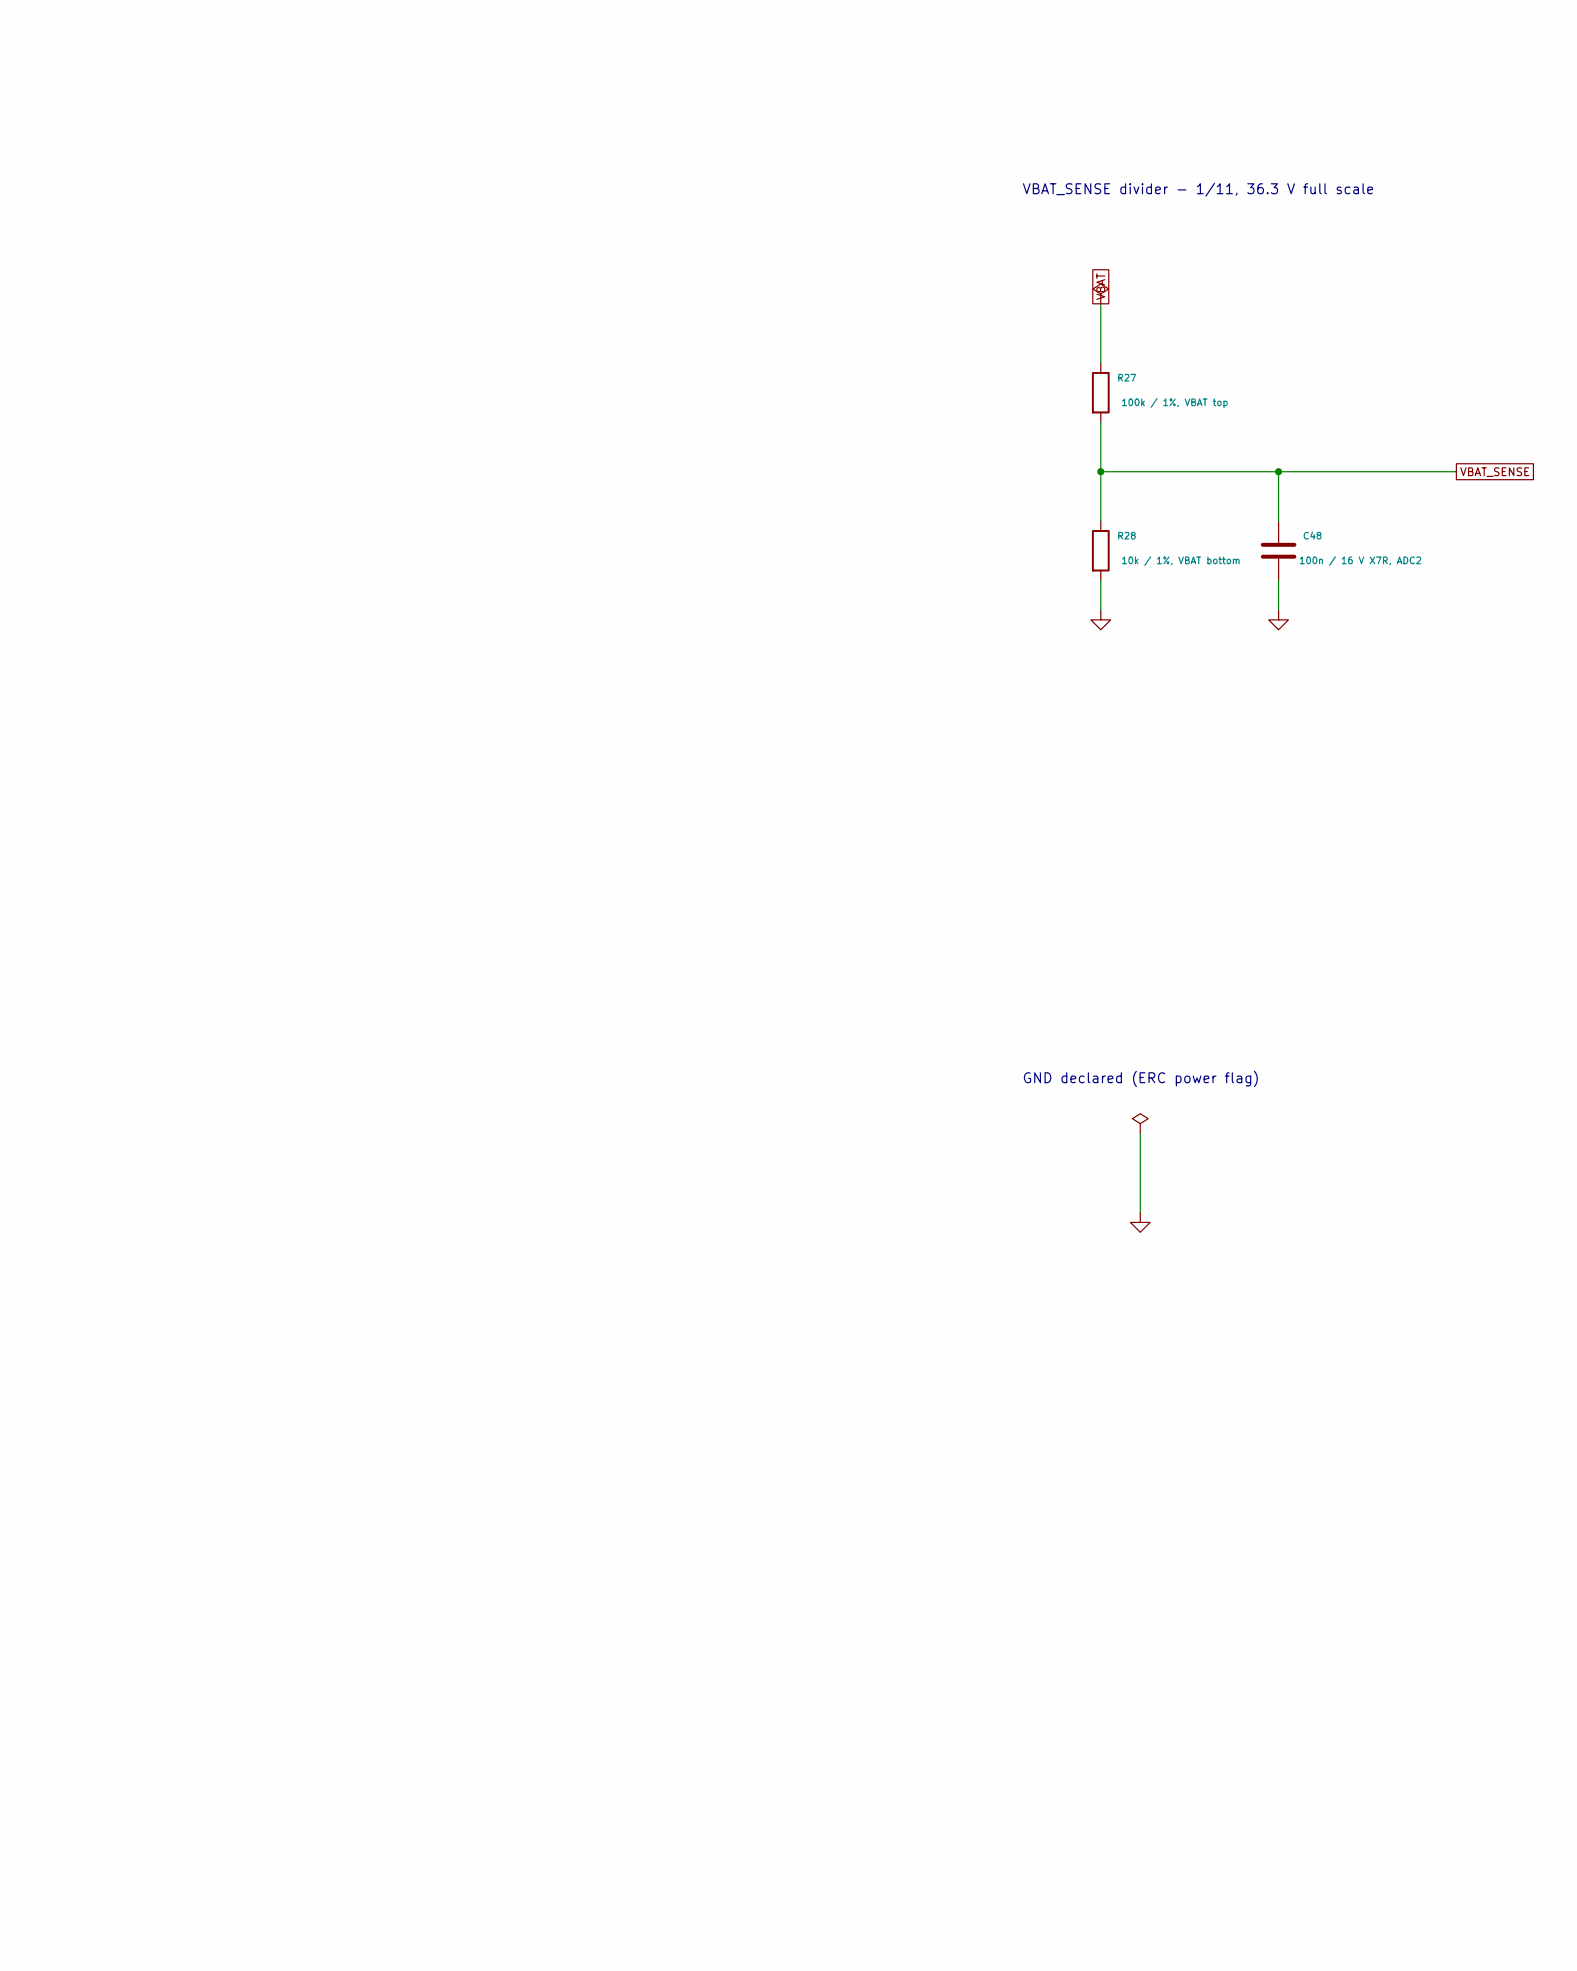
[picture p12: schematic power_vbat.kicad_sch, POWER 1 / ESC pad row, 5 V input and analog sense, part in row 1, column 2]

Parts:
C19: 100u / 6.3 V polymer, ESR <= 40 mOhm (e.g. Panaso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; CP_EIA-3528-21_Kemet-B; LCSC C79109
C48: 100n / 16 V X7R, ADC2; C_0402_1005Metric; LCSC C1525
C78: 100n / 16 V X7R, ADC1 filter; C_0402_1005Metric; LCSC C1525
J3: ESC pads (CURR TX M4 M3 M2 M1 5V GND VBAT); PadRow_1x09_P2.00mm
R27: 100k / 1%, VBAT top; R_0402_1005Metric; LCSC C25741
R28: 10k / 1%, VBAT bottom; R_0402_1005Metric; LCSC C25744
R53: 1k / 1%, CURR series; R_0402_1005Metric; LCSC C11702
R54: 1k, ESC telemetry series; R_0402_1005Metric; LCSC C11702

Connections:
5V_IN: C19.1, J3.7; also elsewhere on the board
CURR_SENSE: C78.1, R53.2; also elsewhere on the board
CURR_SENSE_RAW: J3.1, R53.1
ESC_TELEM: J3.2, R54.1
ESC_TELEM_RX: R54.2; also elsewhere on the board
GND: C19.2, C48.2, C78.2, J3.8, R28.2; also elsewhere on the board
PWM1: J3.6; also elsewhere on the board
PWM2: J3.5; also elsewhere on the board
PWM3: J3.4; also elsewhere on the board
PWM4: J3.3; also elsewhere on the board
VBAT: J3.9, R27.1
VBAT_SENSE: C48.1, R27.2, R28.1; also elsewhere on the board

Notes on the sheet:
ESC PAD ROW J3: CURR, TX, M4, M3, M2, M1, 5V_IN, GND, VBAT. CURR -> R53/C78 -> GPIO42 (ADC2); TX -> R54 -> GPIO32 (PIO UART RX). Motor PWM4/3/2/1 -> GPIO36/38/39/43. Pin 7 receives regulated 5 V from an external buck or boost; C19 is its bulk capacitor. Pin 9 senses raw battery through R27/R28/C48 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
BOARD INPUTS: regulated 5 V at J3 pin 7 from an external converter, plus USB VBUS at J4. External choices: 2S-6S -> 5 V / 3 A buck, or 1S 18650 -> 5 V boost. J3 pin 9 carries raw battery voltage only to the R27/R28 sense divider. 5V_IN supplies servo power (J7 rows 7-10) and Q1. GPS/ELRS use V3V3_S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
POWER 1 - ESC PAD ROW J3 (NINE PADS), 5 V INPUT FROM AN EXTERNAL BEC, VBAT SENSE, ANALOG SENSE. Regulated 5 V arrives on J3 pin 7 as 5V_IN; pin 9 brings raw pack VBAT in as a SENSE wire only.
ESC current sense and KISS telemetry conditioning
ESC pad row
5 V in from the external BEC
TELEMETRY AND ANALOG INPUTS (100 nF at each ADC pin). VBAT_SENSE: R27/R28 100k/10k scale VBAT by 1/11, so the 3.3 V ADC full scale is 36.3 V. A 6S pack at its 25.2 V maximum reads 2.29 V and a 2S pack at 6.0 V reads 0.55 V, so the whole 2-6S window is on-scale with headroom; the divider draws 229 u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
GND declared (ERC power flag)
VBAT_SENSE divider - 1/11, 36.3 V full scale

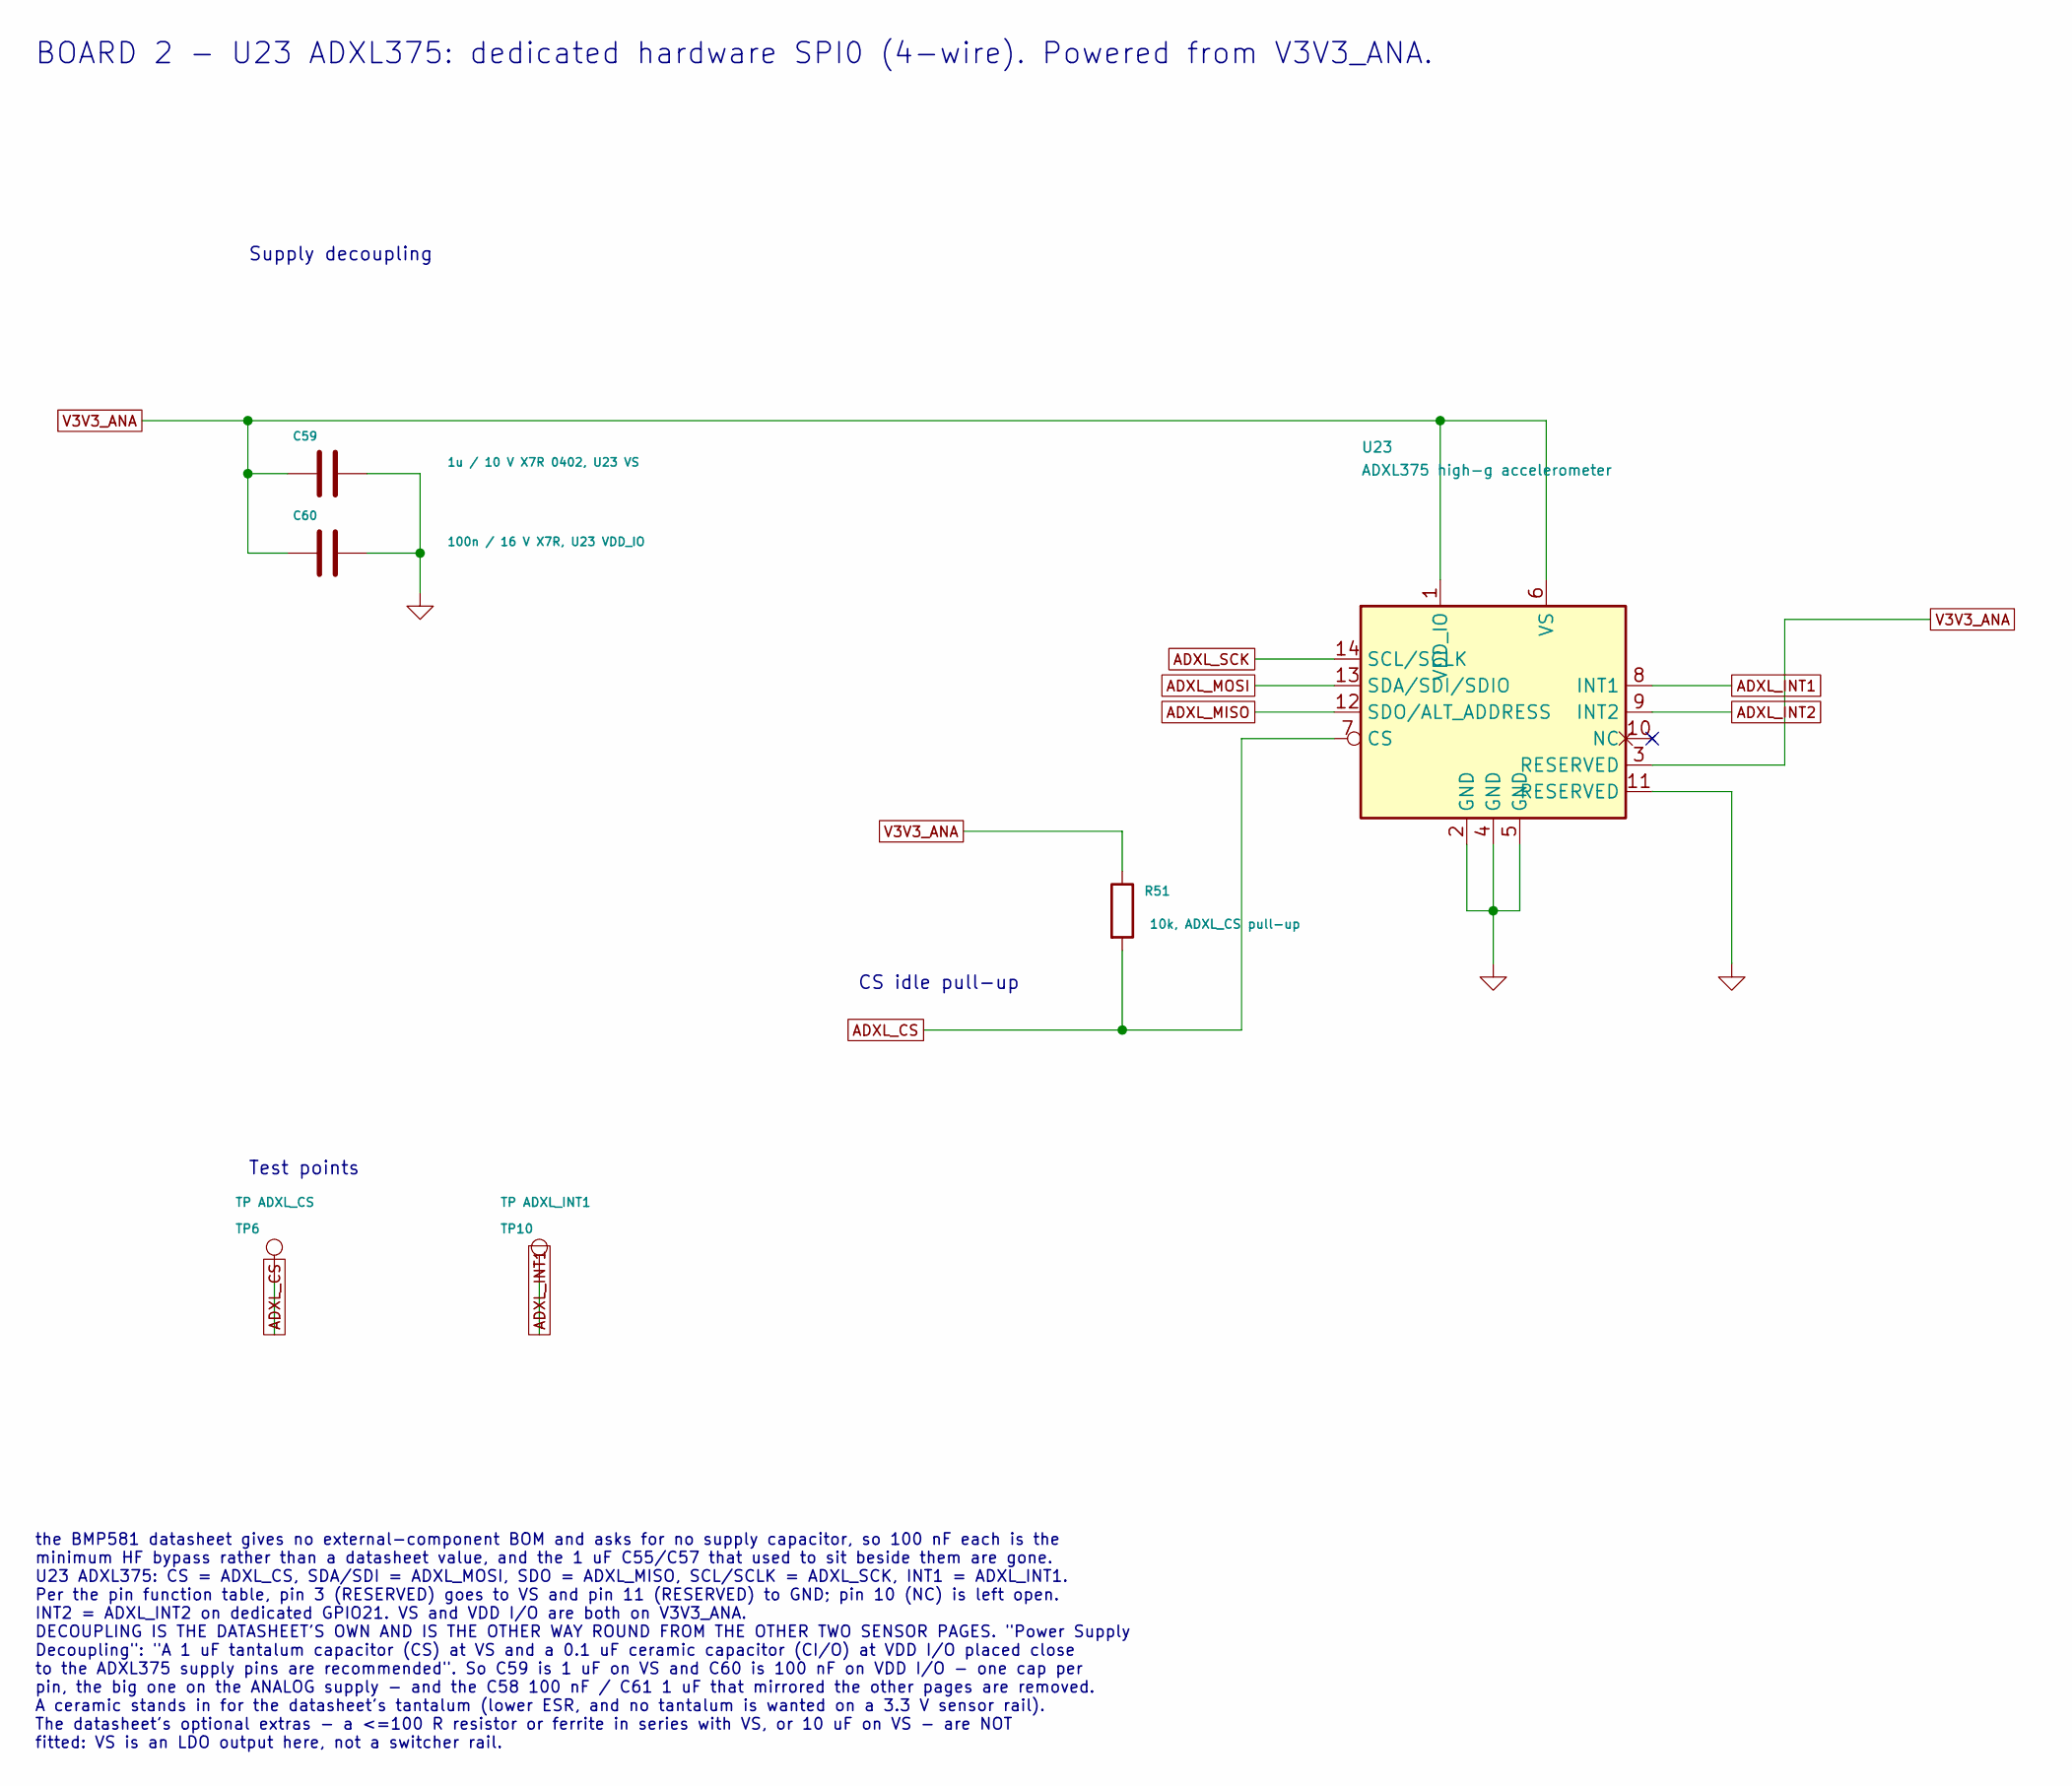
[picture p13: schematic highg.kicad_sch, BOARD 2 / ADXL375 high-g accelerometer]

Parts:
C59: 1u / 10 V X7R 0402, U23 VS; C_0402_1005Metric; LCSC C52923
C60: 100n / 16 V X7R, U23 VDD_IO; C_0402_1005Metric; LCSC C1525
R51: 10k, ADXL_CS pull-up; R_0402_1005Metric; LCSC C25744
TP6: TP ADXL_CS; TestPoint_Pad_1.0x1.0mm_Compact
TP10: TP ADXL_INT1; TestPoint_Pad_1.0x1.0mm_Compact
U23: ADXL375 high-g accelerometer; Analog_LGA-14_3x5mm_P0.8mm_ADXL375; LCSC C579466

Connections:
ADXL_CS: R51.2, TP6.1 (1_1), U23.7 (CS); also elsewhere on the board
ADXL_INT1: TP10.1 (1_1), U23.8 (INT1); also elsewhere on the board
ADXL_INT2: U23.9 (INT2); also elsewhere on the board
ADXL_MISO: U23.12 (SDO/ALT_ADDRESS); also elsewhere on the board
ADXL_MOSI: U23.13 (SDA/SDI/SDIO); also elsewhere on the board
ADXL_SCK: U23.14 (SCL/SCLK); also elsewhere on the board
GND: C59.2, C60.2, U23.2 (GND), U23.4 (GND), U23.5 (GND), U23.11 (RESERVED); also elsewhere on the board
V3V3_ANA: C59.1, C60.1, R51.1, U23.1 (VDD_IO), U23.3 (RESERVED), U23.6 (VS); also elsewhere on the board

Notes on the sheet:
CS idle pull-up
Supply decoupling
Test points
BOARD 2 - U23 ADXL375: dedicated hardware SPI0 (4-wire). Powered from V3V3_ANA.
the BMP581 datasheet gives no external-component BOM and asks for no supply capacitor, so 100 nF each is the minimum HF bypass rather than a datasheet value, and the 1 uF C55/C57 that used to sit beside them are gone. U23 ADXL375: CS = ADXL_CS, SDA/SDI = ADXL_MOSI, SDO = ADXL_MISO, SCL/SCLK = ADXL_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

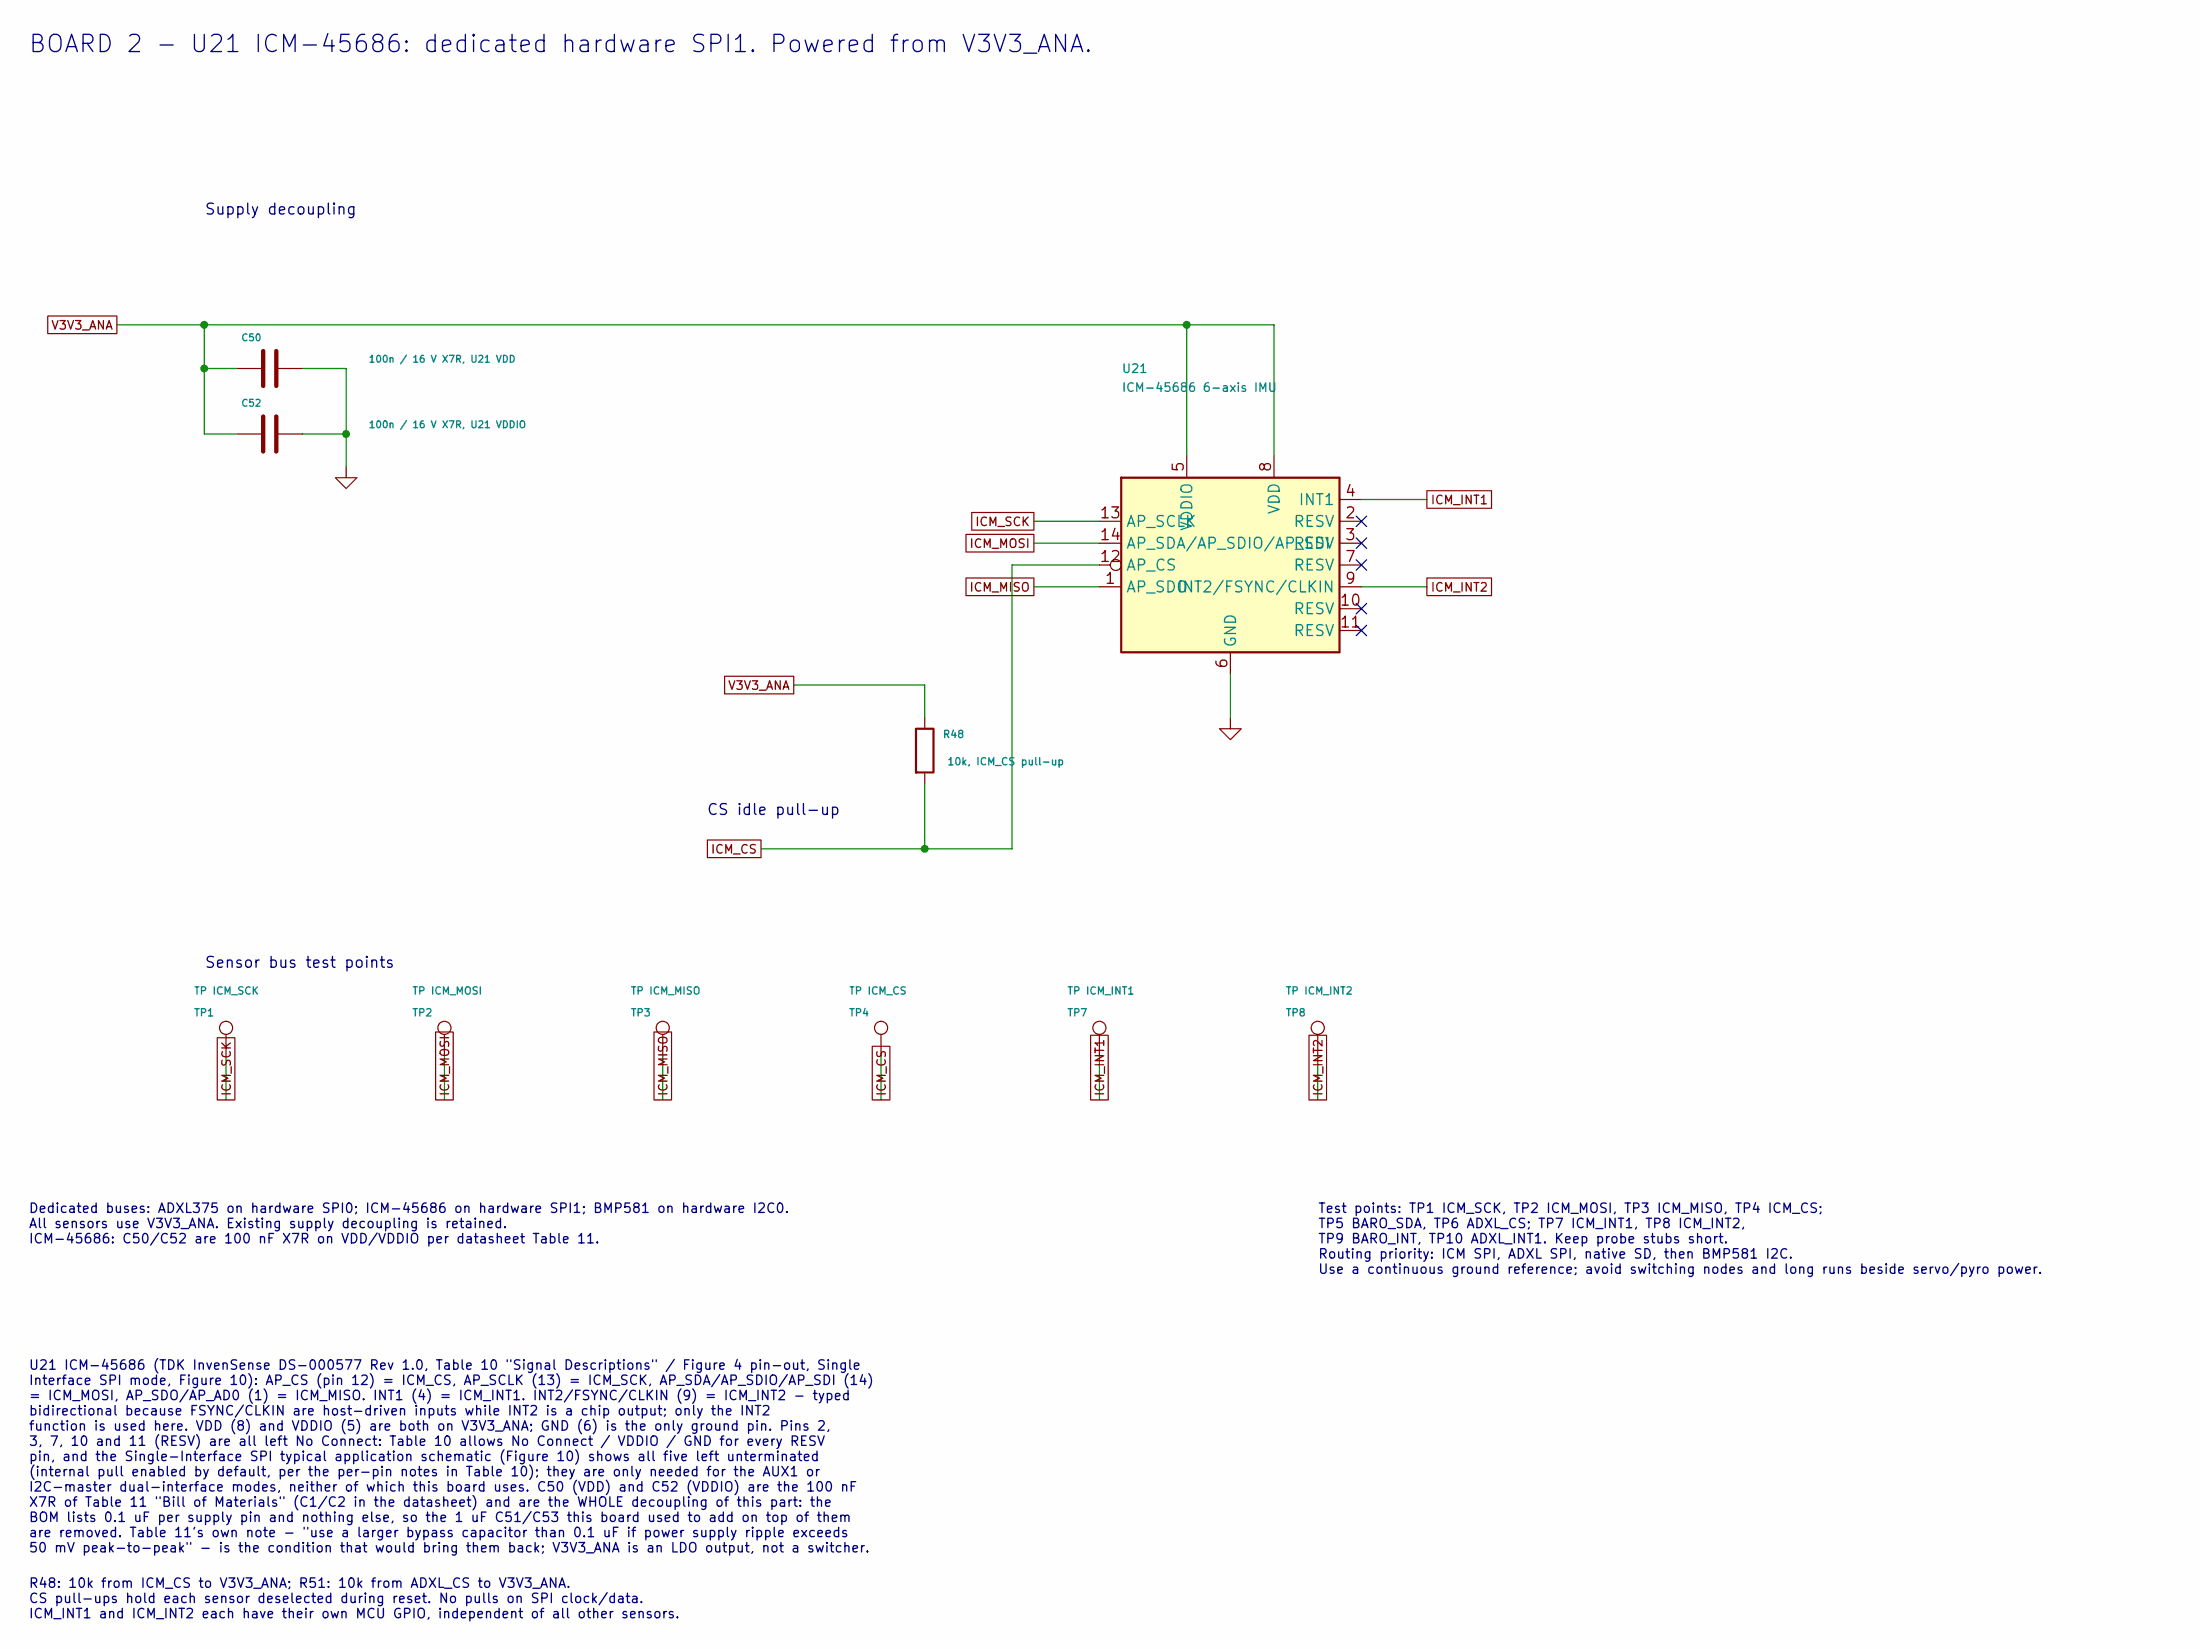
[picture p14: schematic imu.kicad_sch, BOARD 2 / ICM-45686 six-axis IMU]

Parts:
C50: 100n / 16 V X7R, U21 VDD; C_0402_1005Metric; LCSC C1525
C52: 100n / 16 V X7R, U21 VDDIO; C_0402_1005Metric; LCSC C1525
R48: 10k, ICM_CS pull-up; R_0402_1005Metric; LCSC C25744
TP1: TP ICM_SCK; TestPoint_Pad_1.0x1.0mm_Compact
TP2: TP ICM_MOSI; TestPoint_Pad_1.0x1.0mm_Compact
TP3: TP ICM_MISO; TestPoint_Pad_1.0x1.0mm_Compact
TP4: TP ICM_CS; TestPoint_Pad_1.0x1.0mm_Compact
TP7: TP ICM_INT1; TestPoint_Pad_1.0x1.0mm_Compact
TP8: TP ICM_INT2; TestPoint_Pad_1.0x1.0mm_Compact
U21: ICM-45686 6-axis IMU; InvenSense_LGA-14_2.5x3mm_P0.5mm_ICM45686; LCSC C22459454

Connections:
GND: C50.2, C52.2, U21.6 (GND); also elsewhere on the board
ICM_CS: R48.2, TP4.1 (1_1), U21.12 (AP_CS); also elsewhere on the board
ICM_INT1: TP7.1 (1_1), U21.4 (INT1); also elsewhere on the board
ICM_INT2: TP8.1 (1_1), U21.9 (INT2/FSYNC/CLKIN); also elsewhere on the board
ICM_MISO: TP3.1 (1_1), U21.1 (AP_SDO); also elsewhere on the board
ICM_MOSI: TP2.1 (1_1), U21.14 (AP_SDA/AP_SDIO/AP_SDI); also elsewhere on the board
ICM_SCK: TP1.1 (1_1), U21.13 (AP_SCLK); also elsewhere on the board
V3V3_ANA: C50.1, C52.1, R48.1, U21.5 (VDDIO), U21.8 (VDD); also elsewhere on the board

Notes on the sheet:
Sensor bus test points
Supply decoupling
Dedicated buses: ADXL375 on hardware SPI0; ICM-45686 on hardware SPI1; BMP581 on hardware I2C0. All sensors use V3V3_ANA. Existing supply decoupling is retained. ICM-45686: C50/C52 are 100 nF X7R on VDD/VDDIO per datasheet Table 11.
U21 ICM-45686 (TDK InvenSense DS-000577 Rev 1.0, Table 10 "Signal Descriptions" / Figure 4 pin-out, Single Interface SPI mode, Figure 10): AP_CS (pin 12) = ICM_CS, AP_SCLK (13) = ICM_SCK, AP_SDA/AP_SDIO/AP_SDI (14) = ICM_MOSI, AP_SDO/AP_AD0 (1) = ICM_MISO. INT1 (4) = ICM_INT1. INT2/FSYNC/CLKIN (9) 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
R48: 10k from ICM_CS to V3V3_ANA; R51: 10k from ADXL_CS to V3V3_ANA. CS pull-ups hold each sensor deselected during reset. No pulls on SPI clock/data. ICM_INT1 and ICM_INT2 each have their own MCU GPIO, independent of all other sensors.
Test points: TP1 ICM_SCK, TP2 ICM_MOSI, TP3 ICM_MISO, TP4 ICM_CS; TP5 BARO_SDA, TP6 ADXL_CS; TP7 ICM_INT1, TP8 ICM_INT2, TP9 BARO_INT, TP10 ADXL_INT1. Keep probe stubs short. Routing priority: ICM SPI, ADXL SPI, native SD, then BMP581 I2C. Use a continuous ground reference; avoid switching nodes an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
BOARD 2 - U21 ICM-45686: dedicated hardware SPI1. Powered from V3V3_ANA.
CS idle pull-up

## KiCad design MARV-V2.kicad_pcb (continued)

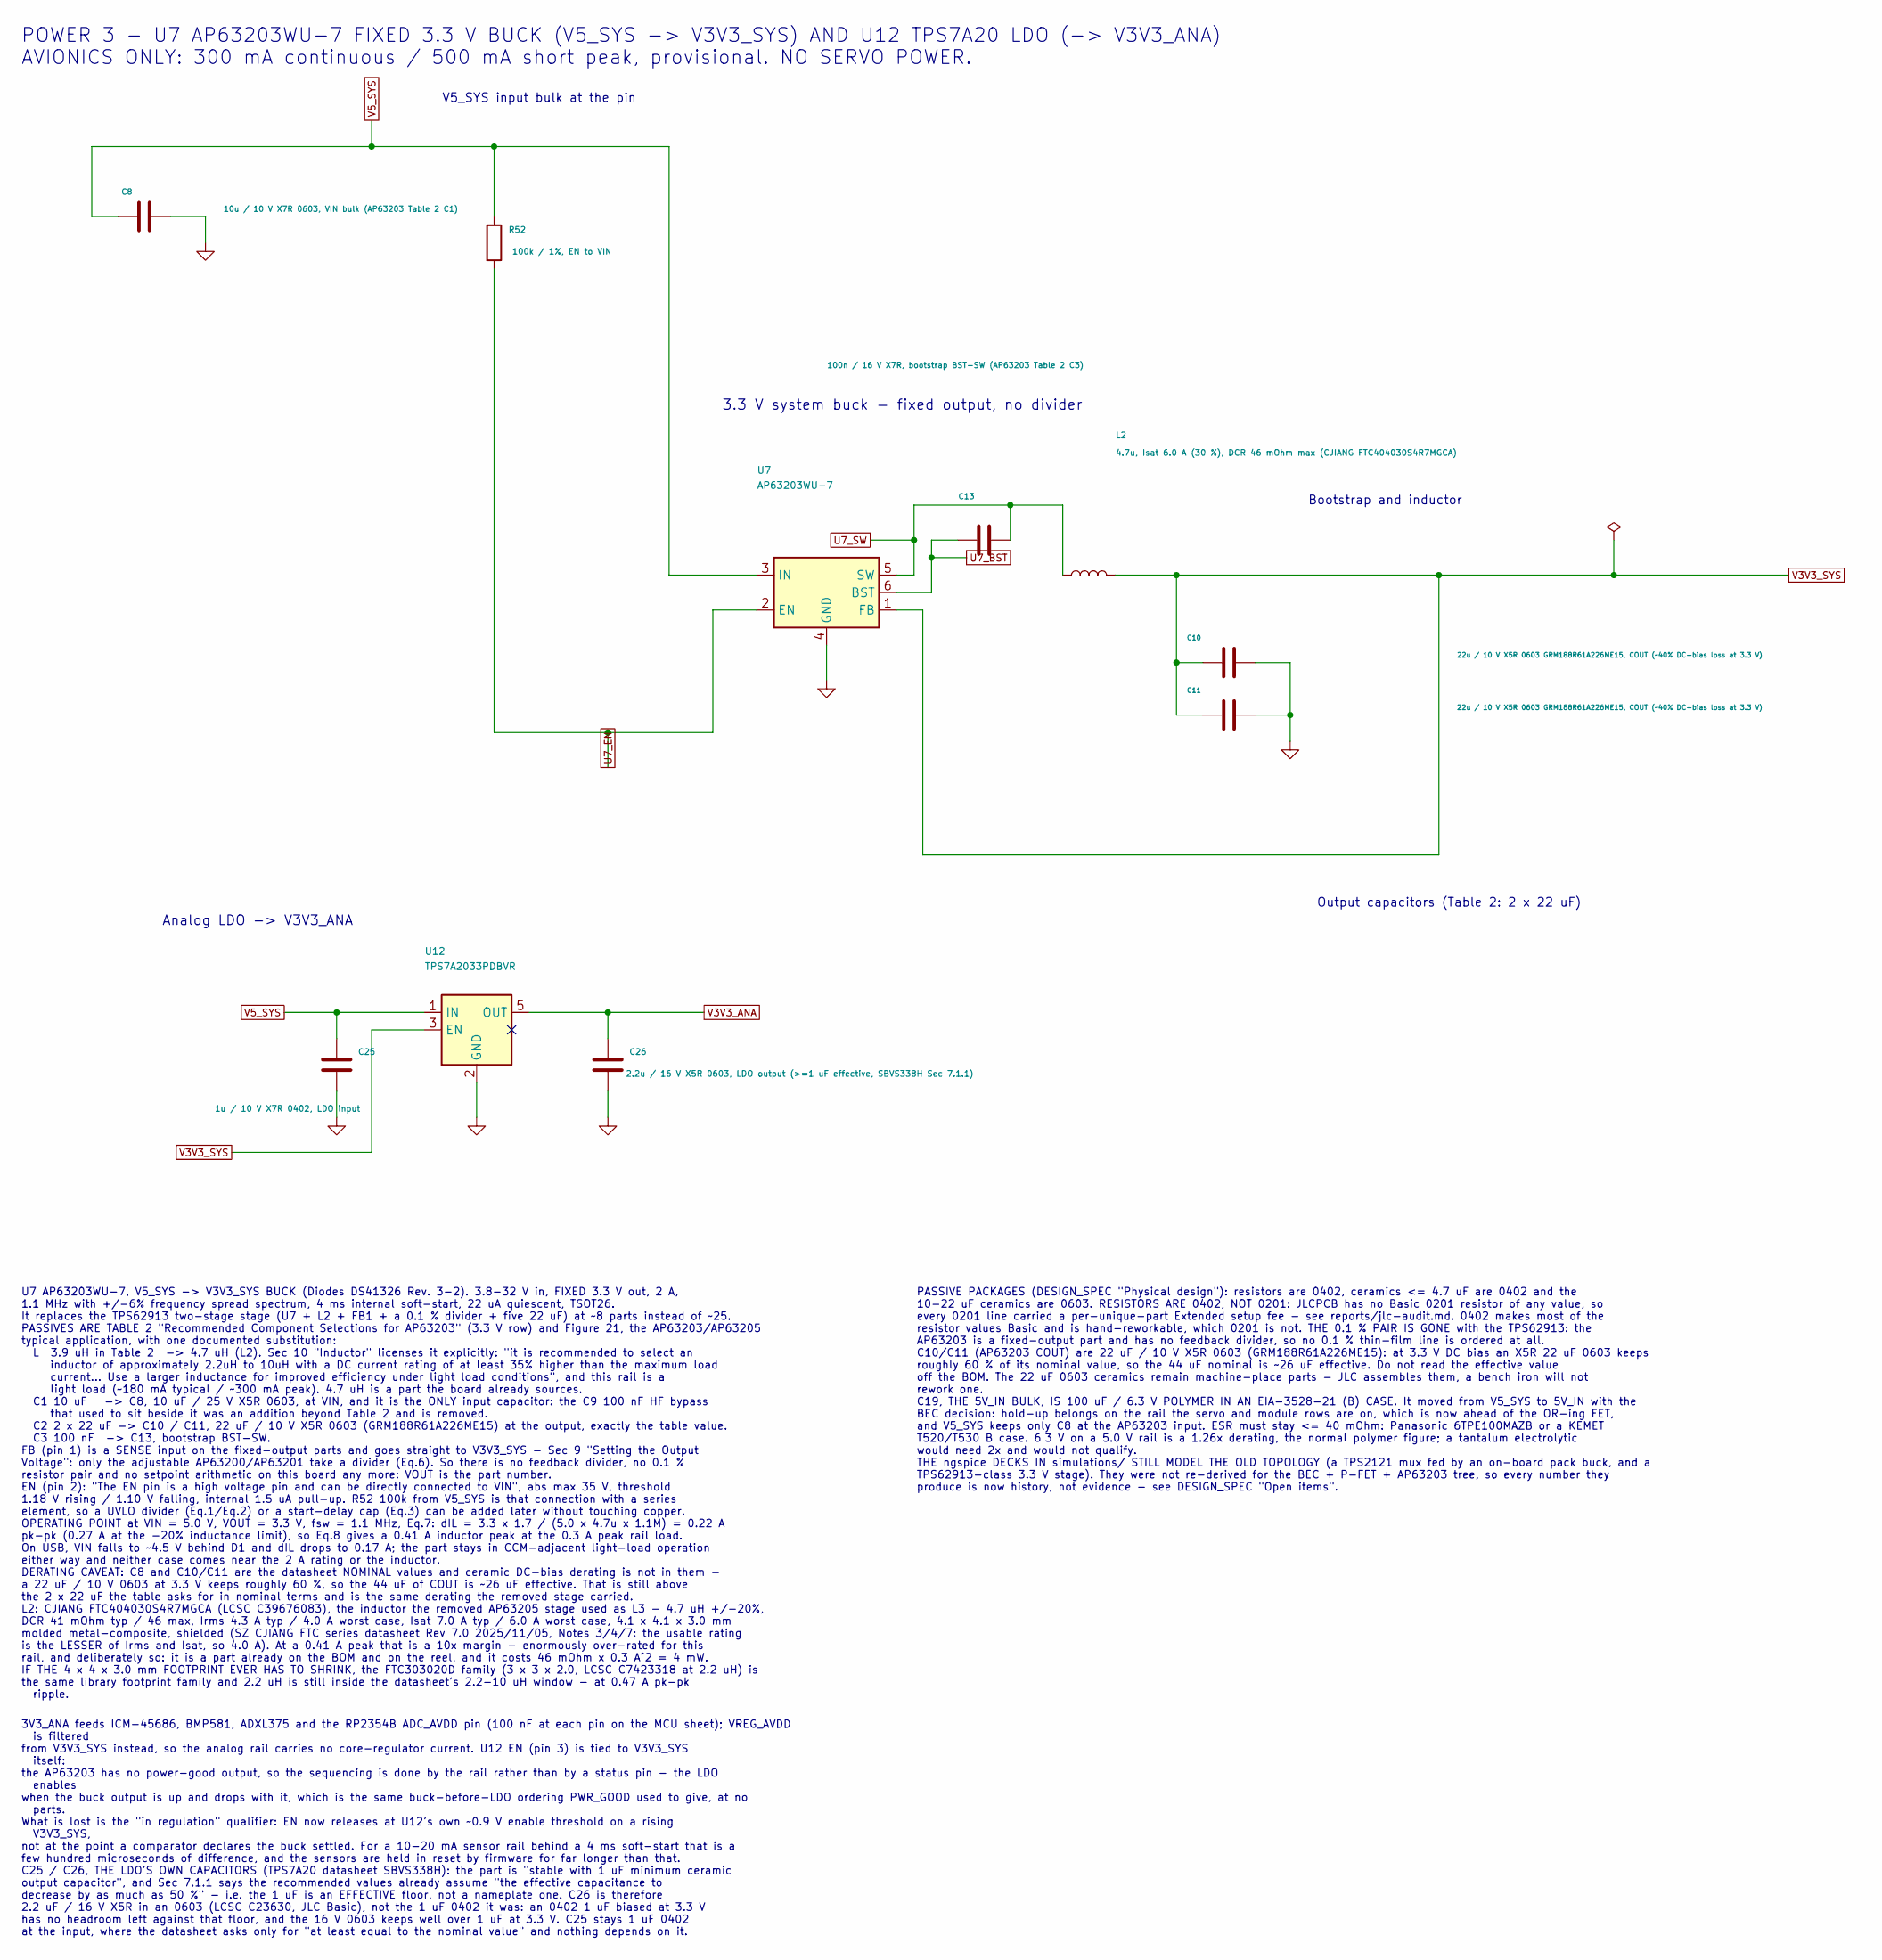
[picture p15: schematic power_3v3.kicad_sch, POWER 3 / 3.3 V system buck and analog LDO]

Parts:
C8: 10u / 10 V X7R 0603, VIN bulk (AP63203 Table 2 C1); C_0603_1608Metric; LCSC C96446
C10, C11: 22u / 10 V X5R 0603 GRM188R61A226ME15, COUT (~40%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; C_0603_1608Metric; LCSC C86295
C13: 100n / 16 V X7R, bootstrap BST-SW (AP63203 Table 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; C_0402_1005Metric; LCSC C1525
C25: 1u / 10 V X7R 0402, LDO input; C_0402_1005Metric; LCSC C52923
C26: 2.2u / 16 V X5R 0603, LDO output (>=1 uF effectiv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; C_0603_1608Metric; LCSC C23630
L2: 4.7u, Isat 6.0 A (30 %), DCR 46 mOhm max (CJIANG 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; L_Changjiang_FTC404030S; LCSC C39676083
R52: 100k / 1%, EN to VIN; R_0402_1005Metric; LCSC C25741
U7: AP63203WU-7; TSOT-23-6; LCSC C780769
U12: TPS7A2033PDBVR; SOT-23-5; LCSC C2862740

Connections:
GND: C8.2, C10.2, C11.2, C25.2, C26.2, U7.4 (GND), U12.2 (GND); also elsewhere on the board
U7_BST: C13.1, U7.6 (BST)
U7_EN: R52.2, U7.2 (EN)
U7_SW: C13.2, L2.1, U7.5 (SW)
V3V3_ANA: C26.1, U12.5 (OUT); also elsewhere on the board
V3V3_SYS: C10.1, C11.1, L2.2, U7.1 (FB), U12.3 (EN); also elsewhere on the board
V5_SYS: C8.1, C25.1, R52.1, U7.3 (IN), U12.1 (IN); also elsewhere on the board

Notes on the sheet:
POWER 3 - U7 AP63203WU-7 FIXED 3.3 V BUCK (V5_SYS -> V3V3_SYS) AND U12 TPS7A20 LDO (-> V3V3_ANA) AVIONICS ONLY: 300 mA continuous / 500 mA short peak, provisional. NO SERVO POWER.
3.3 V system buck - fixed output, no divider
Bootstrap and inductor
V5_SYS input bulk at the pin
Analog LDO -> V3V3_ANA
U7 AP63203WU-7, V5_SYS -> V3V3_SYS BUCK (Diodes DS41326 Rev. 3-2). 3.8-32 V in, FIXED 3.3 V out, 2 A, 1.1 MHz with +/-6% frequency spread spectrum, 4 ms internal soft-start, 22 uA quiescent, TSOT26. It replaces the TPS62913 two-stage stage (U7 + L2 + FB1 + a 0.1 % divider + five 22 uF) at ~8 parts 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
PASSIVE PACKAGES (DESIGN_SPEC "Physical design"): resistors are 0402, ceramics <= 4.7 uF are 0402 and the 10-22 uF ceramics are 0603. RESISTORS ARE 0402, NOT 0201: JLCPCB has no Basic 0201 resistor of any value, so every 0201 line carried a per-unique-part Extended setup fee - see reports/jlc-audit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
3V3_ANA feeds ICM-45686, BMP581, ADXL375 and the RP2354B ADC_AVDD pin (100 nF at each pin on the MCU sheet); VREG_AVDD is filtered from V3V3_SYS instead, so the analog rail carries no core-regulator current. U12 EN (pin 3) is tied to V3V3_SYS itself: the AP63203 has no power-good output, so the seq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
Output capacitors (Table 2: 2 x 22 uF)

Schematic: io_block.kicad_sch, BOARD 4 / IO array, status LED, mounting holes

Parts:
C79: 100n / 16 V X7R, D20 VDD; C_0402_1005Metric; LCSC C1525
D20: WS2812C-2020 RGB; LED_WS2812B-2020_PLCC4_2.0x2.0mm; LCSC C2976072
H1, H2, H3, H4: M3 grommet hole, 4.0 mm, GND ring; MountingHole_4.0mm_Grommet_Pad_Via
J6: IO array signal column (innermost); PinHeader_1x14_P2.54mm_Vertical_IORow; LCSC C2905490
J7: IO array power column (5V / 3V3 per row); PinHeader_1x14_P2.54mm_Vertical_IORow; LCSC C2905490
J8: IO array GND column (board edge); PinHeader_1x14_P2.54mm_Vertical_IORow; LCSC C2905490
R55: 100 / 1%, WS2812 data series; R_0402_1005Metric; LCSC C25076

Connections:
ELRS_RX: J6.3; also elsewhere on the board
ELRS_TX: J6.4; also elsewhere on the board
GND: C79.2, D20.2 (VSS), H1.1 (1_1), H2.1 (1_1), H3.1 (1_1), H4.1 (1_1), J8.1, J8.2, J8.3, J8.4, J8.5, J8.6, J8.7, J8.8, J8.9, J8.10, J8.11, J8.12, J8.13, J8.14; also elsewhere on the board
GPS_RX: J6.1; also elsewhere on the board
GPS_TX: J6.2; also elsewhere on the board
IO_GPIO44: J6.11; also elsewhere on the board
IO_GPIO45: J6.12; also elsewhere on the board
IO_GPIO46: J6.13; also elsewhere on the board
IO_GPIO47: J6.14; also elsewhere on the board
LED_DATA: R55.1; also elsewhere on the board
LED_DIN: D20.3 (DIN), R55.2
MAG_SCL: J6.6; also elsewhere on the board
MAG_SDA: J6.5; also elsewhere on the board
PWM5: J6.7; also elsewhere on the board
PWM6: J6.8; also elsewhere on the board
PWM7: J6.9; also elsewhere on the board
PWM8: J6.10; also elsewhere on the board
V3V3_SYS: J7.1, J7.2, J7.3, J7.4, J7.5, J7.6, J7.7, J7.8, J7.9, J7.10, J7.11, J7.12, J7.13, J7.14; also elsewhere on the board
V5_SYS: C79.1, D20.4 (VDD); also elsewhere on the board

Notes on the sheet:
IO ARRAY - ONE 3-COLUMN x 14-ROW THROUGH-HOLE BLOCK ON THE RIGHT EDGE, 2.54 mm, madflight FC3v2 style. It replaces the old 2x16 left-edge array AND the J12/J13/J14 servo block: every signal that leaves this board except the ESC row (J3) and the SWD pads (J10) now leaves on this one block. COLUMN RU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
WS2812C status LED
Mechanical
IO array - one row per module lead
BOARD 4 - THE 3 x 14 IO BLOCK (J6 SIGNAL / J7 POWER / J8 GND), THE WS2812C STATUS LED AND THE FOUR M3 GROMMET HOLES. Every signal that leaves the board except the ESC row J3 and the DBG pads J10 leaves here.
PWM2 = GPIO39 PWM3 = GPIO38 PWM4 = GPIO36
RAILS ON THE ARRAY: rows 1-6 (GPS, ELRS, magnetometer) and rows 11-14 take V3V3_SYS; rows 7-10 (S5-S8 signal rows) take V3V3_SYS as well. Every row has its own GND pin in the J8 column, so a signal return is never more than 2.54 mm away and no row can be mis-plugged into a neighbour's ground. ROWS 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
IO ARRAY ROW MAP (row n = J6 pin n signal | J7 pin n power | J8 pin n GND) 1 T0 GPS_RX | V3V3_SYS | GND UART1 TX -> GPS RX (GPIO24) 2 R0 GPS_TX | V3V3_SYS | GND UART1 RX <- GPS TX (GPIO25) 3 T1 ELRS_RX | V3V3_SYS | GND UART0 TX -> ELRS RX (GPIO16) 4 R1 ELRS_TX | V3V3_SYS | GND UART0 RX <- ELRS TX (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
MECHANICAL: H1-H4 are the four 4.0 mm grommet holes on the standard 30.5 x 30.5 mm pattern, off-centre in X, each now a PLATED hole with a 6.4 mm GND pad ring stitched by eight 0.6/0.3 mm vias, and a 6.5 mm top-side courtyard for the grommet flange. Pin 1 of every hole is GND, so the frame screws b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
PWM MAP PWM5 = GPIO20 (row 7, S5) PWM6 = GPIO19 (row 8, S6) PWM7 = GPIO15 (row 9, S7) PWM8 = GPIO5 (row 10, S8) ON THE ESC PAD ROW (J3, POWER 1) PWM1 = GPIO43

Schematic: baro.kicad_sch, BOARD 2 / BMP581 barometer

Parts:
C54: 100n / 16 V X7R, U22 VDD; C_0402_1005Metric; LCSC C1525
C56: 100n / 16 V X7R, U22 VDDIO; C_0402_1005Metric; LCSC C1525
R50, R57: 4.7k; R_0402_1005Metric; LCSC C25900
TP5: TP BARO_SDA; TestPoint_Pad_1.0x1.0mm_Compact
TP9: TP BARO_INT; TestPoint_Pad_1.0x1.0mm_Compact
U22: BMP581 barometer; Bosch_LGA-10_2x2mm_BMP581; LCSC C5362283

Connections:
BARO_INT: TP9.1 (1_1), U22.7 (INT); also elsewhere on the board
BARO_SCL: R50.2, U22.2 (SCL); also elsewhere on the board
BARO_SDA: R57.2, TP5.1 (1_1), U22.4 (SDA); also elsewhere on the board
GND: C54.2, C56.2, U22.3 (VSS), U22.5 (ADDR/SDO), U22.8 (VSS), U22.9 (VSS); also elsewhere on the board
V3V3_ANA: C54.1, C56.1, R50.1, R57.1, U22.1 (VDDIO), U22.6 (CSB), U22.10 (VDD); also elsewhere on the board

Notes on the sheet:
Supply decoupling
U22 BMP581: SCK/SCL = BARO_SCL; SDI/SDA = BARO_SDA; INT = BARO_INT (dedicated GPIO13). CSB is hard-wired to VDDIO / V3V3_ANA for I2C mode. SDO/ADDR is tied to GND: 7-bit address 0x46. R50 and R57 are 4.7k pull-ups to V3V3_ANA on SCL and SDA; no pull-downs. VDDIO and VDD use V3V3_ANA; all VSS pins u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
Test points
BOARD 2 - U22 BMP581 BAROMETER: hardware I2C0, powered from V3V3_ANA.
I2C pull-ups: 4.7k

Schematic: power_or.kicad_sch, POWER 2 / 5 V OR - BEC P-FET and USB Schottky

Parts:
D1: 1N5819WS; D_SOD-323; LCSC C191023
Q1: AO3401A; SOT-23; LCSC C15127
R7: 100k / 1%, Q1 gate pull-down; R_0402_1005Metric; LCSC C25741

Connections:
5V_IN: Q1.3 (D); also elsewhere on the board
GND: R7.2; also elsewhere on the board
USB_VBUS: D1.2 (A), Q1.1 (G), R7.1; also elsewhere on the board
V5_SYS: D1.1 (K), Q1.2 (S); also elsewhere on the board

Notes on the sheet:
Gate on USB_VBUS - USB present = Q1 off
USB path - D1 Schottky, the only way USB reaches V5_SYS
BEC path - Q1 P-channel FET, drain 5V_IN, source V5_SYS
5 V INPUT OR: Q1 AO3401A and D1 1N5819WS. Q1 drain = 5V_IN, source = V5_SYS, gate = USB_VBUS. R7 pulls the gate down. D1 anode = USB_VBUS; cathode = V5_SYS. Without USB, Q1's channel carries the external supply after its gate discharges. With USB present, Q1 can be off: D1 and Q1's body diode can s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
POWER 2 - Q1 AO3401A P-FET + D1 1N5819WS SCHOTTKY. 5V_IN (external BEC, J3 pin 7) OR USB_VBUS -> V5_SYS. USB present turns Q1 OFF, so a host can never back-feed the BEC, the servo rows or the ESC.
V5_SYS - the two 3.3 V regulators and the status LED, nothing else
USB_VBUS feeds the D1 Schottky and the Q1 gate on POWER 2 directly; no inrush or current limiting on this sheet, and no data ESD array any more - U8 USBLC6-2SC6 was JLC Extended and is removed (DESIGN_SPEC "Decisions"), so D+/D- go straight from J4 into the 27 R series pair R22/R23, as on the madfl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

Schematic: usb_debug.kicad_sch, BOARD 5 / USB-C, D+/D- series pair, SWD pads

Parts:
C7: 1u / 10 V X7R 0402; C_0402_1005Metric; LCSC C52923
C49: 100n / 16 V X7R, ADC0; C_0402_1005Metric; LCSC C1525
D21: LED white 0603, USB power; LED_0603_1608Metric; LCSC C2290
J4: USB_C_PROGRAM_POWER; USB_C_Receptacle_HRO_TYPE-C-31-M-12; LCSC C165948
J10: SWD header 1x03 2.54 mm (SWCLK GND SWDIO); PinHeader_1x03_P2.54mm_Vertical
R4, R5: 5.1k / 1%; R_0402_1005Metric; LCSC C25905
R22: 27 / 1%, USB D+ series; R_0402_1005Metric; LCSC C2909343
R23: 27 / 1%, USB D- series; R_0402_1005Metric; LCSC C2909343
R29: 10k / 1%, VBUS top; R_0402_1005Metric; LCSC C25744
R30: 15k / 1%, VBUS bottom; R_0402_1005Metric; LCSC C25756
R56: 1k / 1%, USB LED series; R_0402_1005Metric; LCSC C11702

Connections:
GND: C7.2, C49.2, D21.1 (K), J4.A1 (GND), J4.A12 (GND), J4.B1 (GND), J4.B12 (GND), J4.SH (SHIELD), J10.2, R4.2, R5.2, R30.2; also elsewhere on the board
SWCLK: J10.1; also elsewhere on the board
SWDIO: J10.3; also elsewhere on the board
USB_CC1: J4.A5 (CC1), R4.1
USB_CC2: J4.B5 (CC2), R5.1
USB_DM: J4.A7 (D-), J4.B7 (D-), R23.1
USB_DM_RP: R23.2; also elsewhere on the board
USB_DP: J4.A6 (D+), J4.B6 (D+), R22.1
USB_DP_RP: R22.2; also elsewhere on the board
USB_LED_A: D21.2 (A), R56.2
USB_VBUS: C7.1, J4.A4 (VBUS), J4.A9 (VBUS), J4.B4 (VBUS), J4.B9 (VBUS), R29.1, R56.1; also elsewhere on the board
VBUS_SENSE: C49.1, R29.2, R30.1; also elsewhere on the board

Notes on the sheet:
VBUS_SENSE divider (10k / 15k)
D+/D- series pair - no ESD array
D21 / R56 - USB POWER INDICATOR, THE ONLY LED ON THIS BOARD BESIDES THE WS2812C. USB_VBUS -> R56 1 k -> USB_LED_A -> D21 anode, cathode to GND, so it lights whenever a host is plugged in and is dark on BEC-only power - which is exactly the question a bench user asks of this connector, and one the R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
USB_VBUS feeds the D1 Schottky and the Q1 gate on POWER 2 directly; no inrush or current limiting on this sheet, and no data ESD array any more - U8 USBLC6-2SC6 was JLC Extended and is removed (DESIGN_SPEC "Decisions"), so D+/D- go straight from J4 into the 27 R series pair R22/R23, as on the madfl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
SWD landing pads
CC pull-downs
BOARD 5 - J4 USB-C 2.0 RECEPTACLE, THE 27 R D+/D- SERIES PAIR, THE VBUS SENSE DIVIDER AND THE J10 SWD LANDING PADS. NO ON-BOARD USB ESD ARRAY - U8 USBLC6 was removed.
USB-C receptacle
J10 is a 3-pad SWD landing (SWCLK / SWDIO / GND), not a 10-pin Cortex header: solder pads are kept for the two ports that mate with something fixed - the ESC row J3 and this one (DESIGN_SPEC "Connection philosophy"). The debugger reference 3V3 and the debugger-driven reset line of the old 2x05 head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
USB power LED



Board: 4 copper layers, 50.7 x 45.5 mm, 111 parts (14 on the bottom side), 82 nets.

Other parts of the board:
G1: Logo_AxisMarker
G2: Logo_Chevron
G3: Info_SensorTable

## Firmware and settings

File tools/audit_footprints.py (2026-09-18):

#!/usr/bin/env python3
"""Audit every component in the KiCad XML netlist for PCB-layout readiness.

For each <comp> in a `kicad-cli sch export netlist --format kicadxml` export,
checks: footprint assigned, footprint resolvable (via the project and global
fp-lib-table, following nested "Table" type entries such as KiCad 10's
default global table), .kicad_mod file present, referenced 3D model(s)
present, and footprint pad count vs. symbol pin count (from the netlist's
<libparts> section). Pads with a non-numeric designator (mounting/shield
pads like "MP", "SH", "SHIELD") only count toward the pin-count comparison
if the symbol has a pin with that same designator; otherwise they're
mechanical, not electrical, and are excluded from the comparison (the raw,
unfiltered pad count is still available in --json output).

Footprints whose *name* matches --no-3d-ok (default
"^(PadRow_|MountingHole_|TestPoint_)") are exempt from the 3D-model check:
solder pad rows, mechanical holes and bare test-point pads have no body to
model, so a missing model is the correct state, not a defect. They
report OK with the 3D-model cell set to "pads only". The exemption applies ONLY
to the NO_3D_REF status -- a footprint that references a model file that does
not exist still fails with 3D_FILE_MISSING, and every other check is unchanged.

Usage:
    python3 tools/audit_footprints.py [NETLIST_XML] [--json OUT.json] [--no-fail]
                                      [--no-3d-ok REGEX]

    NETLIST_XML defaults to build/checks/netlist.xml (relative to the
    current directory). Regenerate it first, e.g. into a scratch location
    while the schematic is in flux:

        kicad-cli sch export netlist MARV-V2.kicad_sch --format kicadxml -o /path/to/scratch/netlist.xml
        python3 tools/audit_footprints.py /path/to/scratch/netlist.xml

Prints a markdown table (Ref | Value | Symbol | Footprint | FP file | 3D
model | Status) sorted by status then reference, a per-status summary count,
and a deduplicated list of footprints needing action with the refs that use
them. Exits non-zero if any component is not OK, unless --no-fail is given.
Standard library only; no third-party packages.
"""
import argparse
import json
import os
import re
import sys
import xml.etree.ElementTree as ET
from pathlib import Path

ROOT = Path(__file__).resolve().parents[1]

STATUS_ORDER = ['OK', 'NO_FOOTPRINT', 'FP_NOT_FOUND', 'NO_3D_REF', '3D_FILE_MISSING', 'PIN_MISMATCH']
# Severity order used to pick a single Status per row when more than one issue applies.
STATUS_PRIORITY = ['NO_FOOTPRINT', 'FP_NOT_FOUND', '3D_FILE_MISSING', 'NO_3D_REF', 'PIN_MISMATCH', 'OK']

MPN_FIELDS = {'mpn'}
MANUFACTURER_FIELDS = {'manufacturer', 'mfr', 'mfg'}
PARTNUM_FIELDS = {'part number', 'partnumber', 'part_number', 'manufacturer part number',
                   'manufacturer_part_number', 'mfr part number', 'mfr_pn'}

GLOBAL_FP_LIB_TABLE_CANDIDATES = [
    Path.home() / '.config/kicad/10.0/fp-lib-table',
    Path.home() / '.config/kicad/9.0/fp-lib-table',
]

DEFAULT_ENV_FALLBACKS = {
    'KICAD10_FOOTPRINT_DIR': '/usr/share/kicad/footprints',
    'KICAD10_3DMODEL_DIR': '/usr/share/kicad/3dmodels',
    'KICAD9_FOOTPRINT_DIR': '/usr/share/kicad/footprints',
    'KICAD9_3DMODEL_DIR': '/usr/share/kicad/3dmodels',
}

# ---- minimal s-expression reader, shared by fp-lib-table and .kicad_mod parsing ----

TOKEN_RE = re.compile(r'"(?:\\.|[^"\\])*"|[()]|[^\s()]+')


def parse_sexpr(text):
    toks = TOKEN_RE.findall(text)
    stack, root = [], None
    for tok in toks:
        if tok == '(':
            node = []
            if stack:
                stack[-1].append(node)
            stack.append(node)
        elif tok == ')':
            root = stack.pop()
        else:
            stack[-1].append(tok)
    return root


def unquote(s):
    return json.loads(s) if s.startswith('"') else s


def first(node, key):
    return next((v for v in node if isinstance(v, list) and v and v[0] == key), None)


def walk(node):
    if isinstance(node, list):
        yield node
        for child in node:
            yield from walk(child)


def natural_key(ref):
    m = re.match(r'^([A-Za-z_#]*)(\d+)?(.*)$', ref or '')
    if not m:
        return (ref or '', -1, '')
    prefix, num, rest = m.groups()
    return (prefix, int(num) if num else -1, rest)


# ---- environment / fp-lib-table resolution ----

def build_env():
    env = dict(os.environ)
    env['KIPRJMOD'] = str(ROOT)
    for var, default in DEFAULT_ENV_FALLBACKS.items():
        env.setdefault(var, default)
    return env


def expand_vars(text, env):
    def repl(m):
        return env.get(m.group(1), m.group(0))
    return re.sub(r'\$\{([^}]+)\}', repl, text)


def merge_fp_lib_table(path, dest, visited, env):
    """Merge lib nickname -> expanded directory URI into dest. Entries whose
    type is "Table" point at another fp-lib-table file; that file's entries
    are merged inline under their own names (not nested under the parent
    entry's nickname), matching how KiCad 10's default global table is a
    single "Table" entry pointing at the real ~150-library list."""
    if path is None or not path.exists():
        return
    resolved = path.resolve()
    if resolved in visited:
        return
    visited.add(resolved)
    try:
        tree = parse_sexpr(path.read_text())
    except (OSError, UnicodeDecodeError):
        return
    if tree is None:
        return
    for node in walk(tree):
        if not (node and node[0] == 'lib'):
            continue
        name_node, type_node, uri_node = first(node, 'name'), first(node, 'type'), first(node, 'uri')
        if not name_node or not uri_node:
            continue
        name = unquote(name_node[1])
        typ = unquote(type_node[1]) if type_node else ''
        uri = expand_vars(unquote(uri_node[1]), env)
        if typ.strip().lower() == 'table':
            merge_fp_lib_table(Path(uri), dest, visited, env)
        elif name not in dest:
            dest[name] = uri


def load_fp_lib_table(env):
    dest = {}
    visited = set()
    # Project table takes priority over the global table on name collisions.
    merge_fp_lib_table(ROOT / 'fp-lib-table', dest, visited, env)
    for candidate in GLOBAL_FP_LIB_TABLE_CANDIDATES:
        if candidate.exists():
            merge_fp_lib_table(candidate, dest, visited, env)
            break
    return dest


# ---- .kicad_mod inspection ----

FP_CACHE = {}


def inspect_footprint(fp_path, env):
    """Return (pad_numbers set, [(model_path, exists), ...]) for a .kicad_mod file."""
    key = str(fp_path)
    if key in FP_CACHE:
        return FP_CACHE[key]
    try:
        tree = parse_sexpr(fp_path.read_text())
    except (OSError, UnicodeDecodeError):
        result = (set(), [])
        FP_CACHE[key] = result
        return result
    pads = set()
    models = []
    if tree is not None:
        for node in walk(tree):
            if node and node[0] == 'pad' and len(node) > 1 and isinstance(node[1], str):
                num = unquote(node[1])
                if num != '':
                    pads.add(num)
            elif node and node[0] == 'model' and len(node) > 1 and isinstance(node[1], str):
                raw = unquote(node[1])
                model_path = Path(expand_vars(raw, env))
                models.append((str(model_path), model_path.exists()))
    result = (pads, models)
    FP_CACHE[key] = result
    return result


# ---- netlist parsing ----

def get_field(fields, candidates):
    for name, value in fields.items():
        if name.strip().lower() in candidates and value:
            return value
    return ''


def parse_netlist(xml_path):
    root = ET.parse(xml_path).getroot()
    components_el = root.find('components')
    if components_el is None:
        raise SystemExit(f'{xml_path}: no <components> section (not a kicadxml netlist export?)')

    libpart_pins = {}
    libparts_el = root.find('libparts')
    if libparts_el is not None:
        for lp in libparts_el.findall('libpart'):
            key = (lp.get('lib'), lp.get('part'))
            nums = set()
            pins_el = lp.find('pins')
            if pins_el is not None:
                for pin in pins_el.findall('pin'):
                    num = pin.get('num')
                    if num:
                        nums.add(num)
            libpart_pins[key] = nums

    comps = []
    for c in components_el.findall('comp'):
        ref = c.get('ref')
        value_el = c.find('value')
        value = (value_el.text or '') if value_el is not None else ''
        fp_el = c.find('footprint')
        footprint = (fp_el.text or '').strip() if fp_el is not None else ''
        libsource = c.find('libsource')
        lib = libsource.get('lib') if libsource is not None else ''
        part = libsource.get('part') if libsource is not None else ''
        sheet = ''
        for prop in c.findall('property'):
            if prop.get('name') == 'Sheetname':
                sheet = prop.get('value', '')
                break
        fields = {}
        fields_el = c.find('fields')
        if fields_el is not None:
            for f in fields_el.findall('field'):
                fields[f.get('name', '')] = (f.text or '').strip()
        comps.append({
            'ref': ref,
            'value': value.strip(),
            'lib': lib,
            'part': part,
            'symbol': f'{lib}:{part}',
            'footprint': footprint,
            'sheet': sheet,
            'mpn': get_field(fields, MPN_FIELDS),
            'manufacturer': get_field(fields, MANUFACTURER_FIELDS),
            'part_number': get_field(fields, PARTNUM_FIELDS),
            'pin_count': len(libpart_pins.get((lib, part), set())) if (lib, part) in libpart_pins else None,
        })
    return comps, libpart_pins


# ---- per-component resolution ----

def md_escape(text):
    return (text or '').replace('|', '\\|').replace('\n', ' ')


DEFAULT_NO_3D_OK = r'^(PadRow_|MountingHole_|TestPoint_)'


def resolve_component(comp, fp_table, env, pin_nums, no_3d_ok=None):
    """pin_nums is the symbol's set of pin numbers (from <libparts>), or None
    if no libpart data is available for this component's lib:part.

    no_3d_ok is a compiled regex matched against the footprint NAME (the part
    after 'lib:'); a match means "this footprint is not supposed to have a 3D
    model", so NO_3D_REF is suppressed."""
    row = dict(comp)
    row['fp_file_cell'] = '—'
    row['model_cell'] = '—'
    row['fp_path'] = None
    row['fp_resolved'] = False
    row['pad_count'] = None
    row['pad_count_raw'] = None
    row['models'] = []
    issues = set()

    footprint = comp['footprint']
    if not footprint:
        issues.add('NO_FOOTPRINT')
        row['status'] = 'NO_FOOTPRINT'
        return row

    if ':' not in footprint:
        issues.add('FP_NOT_FOUND')
        row['fp_file_cell'] = "malformed footprint field (no 'lib:name')"
        row['status'] = 'FP_NOT_FOUND'
        return row

    fp_lib, fp_name = footprint.split(':', 1)
    lib_dir = fp_table.get(fp_lib)
    if lib_dir is None:
        issues.add('FP_NOT_FOUND')
        row['fp_file_cell'] = f"library '{fp_lib}' not in fp-lib-table"
        row['status'] = 'FP_NOT_FOUND'
        return row

    fp_path = Path(lib_dir) / f'{fp_name}.kicad_mod'
    if not fp_path.exists():
        issues.add('FP_NOT_FOUND')
        row['fp_file_cell'] = f'{fp_lib}.pretty/{fp_name}.kicad_mod not found'
        row['status'] = 'FP_NOT_FOUND'
        return row

    row['fp_path'] = str(fp_path)
    row['fp_resolved'] = True
    pads, models = inspect_footprint(fp_path, env)
    row['pad_count_raw'] = len(pads)
    # Pads with a purely numeric designator always count. Pads with a
    # non-numeric designator (mounting/shield pads like "MP", "SH",
    # "SHIELD") only count toward the mismatch check if the symbol itself
    # has a pin with that same designator; otherwise they're mechanical,
    # not electrical, and are excluded. When no libpart pin data is
    # available at all, fall back to the raw pad count unfiltered.
    if pin_nums is None:
        effective_pads = pads
    else:
        effective_pads = {p for p in pads if p.isdigit() or p in pin_nums}
    row['pad_count'] = len(effective_pads)
    row['models'] = [{'path': p, 'exists': e} for p, e in models]

    pin_count = comp['pin_count']
    pin_note = f' / {pin_count} pins' if pin_count is not None else ''
    row['fp_file_cell'] = f'{fp_name}.kicad_mod ({len(effective_pads)} pads{pin_note})'

    if not models:
        if no_3d_ok is not None and no_3d_ok.search(fp_name):
            row['model_cell'] = 'pads only'
            row['no_3d_ok'] = True
        else:
            issues.add('NO_3D_REF')
            row['model_cell'] = '(no 3D model referenced)'
    else:
        missing = [p for p, e in models if not e]
        if missing:
            issues.add('3D_FILE_MISSING')
            row['model_cell'] = ', '.join(
                f'{Path(p).name} MISSING' if not e else Path(p).name for p, e in models)
        else:
            row['model_cell'] = ', '.join(Path(p).name for p, _ in models)

    if pin_count is not None and pin_count != len(effective_pads):
        issues.add('PIN_MISMATCH')

    row['status'] = next(s for s in STATUS_PRIORITY if s in issues) if issues else 'OK'
    return row


def main():
    ap = argparse.ArgumentParser(description=__doc__, formatter_class=argparse.RawDescriptionHelpFormatter)
    ap.add_argument('netlist', nargs='?', default='build/checks/netlist.xml',
                     help='kicadxml netlist export (default: build/checks/netlist.xml)')
    ap.add_argument('--json', metavar='PATH', help='also write machine-readable results to PATH')
    ap.add_argument('--no-fail', action='store_true', help='exit 0 even if issues are found')
    ap.add_argument('--no-3d-ok', metavar='REGEX', default=DEFAULT_NO_3D_OK,
                     help='footprint-name regex whose matches need no 3D model; they report OK with '
                          '"pads only" (default: %(default)s). Pass an empty string to disable.')
    args = ap.parse_args()
    no_3d_ok = re.compile(args.no_3d_ok) if args.no_3d_ok else None

    xml_path = Path(args.netlist)
    if not xml_path.exists():
        print(f'error: netlist not found: {xml_path}', file=sys.stderr)
        sys.exit(2)

    env = build_env()
    fp_table = load_fp_lib_table(env)
    comps, libpart_pins = parse_netlist(xml_path)
    rows = [resolve_component(c, fp_table, env, libpart_pins.get((c['lib'], c['part'])), no_3d_ok)
            for c in comps]
    rows.sort(key=lambda r: (STATUS_ORDER.index(r['status']), natural_key(r['ref'])))

    print('| Ref | Value | Symbol | Footprint | FP file | 3D model | Status |')
    print('| --- | --- | --- | --- | --- | --- | --- |')
    for r in rows:
        print('| {} | {} | {} | {} | {} | {} | {} |'.format(
            md_escape(r['ref']), md_escape(r['value']), md_escape(r['symbol']),
            md_escape(r['footprint']) or '\u2014', md_escape(r['fp_file_cell']),
            md_escape(r['model_cell']), r['status']))

    counts = {s: 0 for s in STATUS_ORDER}
    for r in rows:
        counts[r['status']] += 1
    print()
    print('## Summary')
    print()
    print('| Status | Count |')
    print('| --- | --- |')
    for s in STATUS_ORDER:
        print(f'| {s} | {counts[s]} |')
    print()
    total_issues = len(rows) - counts['OK']
    print(f'Total components: {len(rows)}; OK: {counts["OK"]}; needing action: {total_issues}')

    needing_action = {}
    for r in rows:
        if r['status'] == 'OK':
            continue
        key = r['footprint'] if r['footprint'] else f"(no footprint \u2014 symbol {r['symbol']})"
        needing_action.setdefault(key, []).append(r['ref'])

    print()
    print('## Footprints needing action')
    print()
    if not needing_action:
        print('None.')
    else:
        for fp in sorted(needing_action):
            refs = sorted(needing_action[fp], key=natural_key)
            print(f'- `{fp}`: {", ".join(refs)}')

    if args.json:
        json_path = Path(args.json)
        json_path.write_text(json.dumps({
            'netlist': str(xml_path),
            'components': rows,
            'summary': counts,
            'footprints_needing_action': needing_action,
        }, indent=2))
        print(f'\nJSON written to {json_path}', file=sys.stderr)

    if total_issues and not args.no_fail:
        sys.exit(1)
    sys.exit(0)


if __name__ == '__main__':
    main()

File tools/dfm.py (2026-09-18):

#!/usr/bin/env python3
"""Check/apply the MARV DFM profile without regenerating board geometry."""
import argparse
import copy
import difflib
import json
import os
from pathlib import Path
import re
import shutil
import subprocess
import sys
import tempfile

ROOT = Path(__file__).resolve().parents[1]
PROFILE = ROOT / 'config/dfm/jlcpcb.json'
TEMPLATE = PROFILE.with_suffix('.kicad_dru')
BEGIN = '# BEGIN MANAGED MARV JLCPCB DFM'
END = '# END MANAGED MARV JLCPCB DFM'
TOKEN = re.compile(r'"(?:\\.|[^"\\])*"|[()]|[^\s()]+')


def tokens(text):
    return TOKEN.findall(text)


def children(text):
    """Direct child spans, respecting escaped strings; never reserialize geometry."""
    depth = 0
    start = None
    result = []
    for match in TOKEN.finditer(text):
        if match[0] == '(':
            if depth == 1:
                start = match.start()
            depth += 1
        elif match[0] == ')':
            depth -= 1
            if depth < 0:
                raise ValueError('Unbalanced KiCad expression')
            if depth == 1 and start is not None:
                result.append((start, match.end()))
    if depth:
        raise ValueError('Unbalanced KiCad expression')
    return result


def locate(text, key):
    matches = [(a, b) for a, b in children(text)
               if tokens(text[a:b])[1:1 + len(key)] == list(key)]
    if len(matches) > 1:
        raise ValueError(f'Duplicate KiCad setting: {key}')
    return matches[0] if matches else None


def node(text, *key):
    span = locate(text, key)
    if span is None:
        raise ValueError(f'Missing KiCad setting: {key}')
    return text[slice(*span)]


def replace_node(text, key, replacement, indent='\t\t'):
    span = locate(text, key)
    if span is not None:
        old = text[slice(*span)]
        if tokens(old) == tokens(replacement):
            return text  # preserve existing formatting and mtime on no-op
        return text[:span[0]] + replacement + text[span[1]:]
    end = text.rfind(')')
    return text[:end].rstrip() + '\n' + indent + replacement + '\n' + text[end:]


def board_settings(text, profile):
    general = node(text, 'general')
    thickness = float(tokens(node(general, 'thickness'))[2])
    if abs(thickness - profile['board_thickness_mm']) > 1e-6:
        raise ValueError('Profile requires the existing 1.6 mm MARV board')
    setup = node(text, 'setup')
    stack = node(setup, 'stackup')
    copper = {}
    for a, b in children(stack):
        part = stack[a:b]
        if tokens(part)[1] != 'layer':
            continue
        if tokens(node(part, 'type'))[2] == '"copper"':
            copper[json.loads(tokens(part)[2])] = float(tokens(node(part, 'thickness'))[2])
    expected = profile['copper_mm']
    if copper.keys() != expected.keys() or any(abs(copper[k] - expected[k]) > 1e-6 for k in copper):
        raise ValueError('Copper stackup differs; review the profile instead of changing the board stackup')
    for layer in ['F.Mask', 'B.Mask']:
        key = ('layer', json.dumps(layer))
        part = node(stack, *key)
        part = replace_node(part, ('color',), f'(color {json.dumps(profile["mask_color"])})', '\t\t\t\t')
        stack = replace_node(stack, key, part)
    stack = replace_node(stack, ('copper_finish',), f'(copper_finish {json.dumps(profile["finish"])})')
    setup = replace_node(setup, ('stackup',), stack)
    for key, value in profile['setup'].items():
        setup = replace_node(setup, (key,), value)
    return replace_node(text, ('setup',), setup)


def merge(target, patch):
    for key, value in patch.items():
        if isinstance(value, dict):
            if key not in target:
                target[key] = {}
            if not isinstance(target[key], dict):
                raise ValueError(f'Unexpected project setting type: {key}')
            merge(target[key], value)
        else:
            target[key] = copy.deepcopy(value)


def project_settings(text, profile):
    original = json.loads(text)
    updated = copy.deepcopy(original)
    patch = copy.deepcopy(profile['project'])
    net_patch = patch.pop('net_settings')
    merge(updated, patch)
    nets = updated.setdefault('net_settings', {})
    managed = {c['name'] for c in net_patch['classes']} | set(profile['retired_classes'])
    extra_classes = [c for c in nets.get('classes', []) if c['name'] not in managed]
    existing = {c['name']: c for c in nets.get('classes', [])}
    classes = []
    for values in net_patch['classes']:
        entry = copy.deepcopy(existing.get(values['name'], existing.get('Default', {})))
        entry.update(values)
        classes.append(entry)
    nets['classes'] = classes + extra_classes
    extra_patterns = [p for p in nets.get('netclass_patterns', []) if p['netclass'] not in managed]
    nets['netclass_patterns'] = copy.deepcopy(net_patch['netclass_patterns']) + extra_patterns
    if updated == original:
        return text
    return json.dumps(updated, indent=2) + '\n'


def custom_rules(text, template):
    version = '(version 1)'
    if not template.startswith(version):
        raise ValueError('Expected version 1 custom-rule template')
    body = template[len(version):].strip()
    block = BEGIN + '\n' + body + '\n' + END
    if BEGIN in text or END in text:
        if text.count(BEGIN) != 1 or text.count(END) != 1 or text.index(BEGIN) > text.index(END):
            raise ValueError('Malformed managed custom-rule markers')
        a, b = text.index(BEGIN), text.index(END) + len(END)
        return text[:a] + block + text[b:]
    if not text.strip() or text.strip() == template.strip():
        return version + '\n\n' + block + '\n'
    # Never discard an unrecognized rules file. Adopt it only after manual review.
    raise ValueError('Unmanaged custom rules exist; retain them outside a reviewed managed block')


def plan(project, profile, template):
    files = {project: project_settings, project.with_suffix('.kicad_pcb'): board_settings}
    changes = {}
    for path, transform in files.items():
        old = path.read_text()
        new = transform(old, profile)
        if new != old:
            changes[path] = (old, new)
    path = project.with_suffix('.kicad_dru')
    old = path.read_text() if path.exists() else ''
    new = custom_rules(old, template)
    if new != old:
        changes[path] = (old, new)
    return changes
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

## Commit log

2026-09-15 MARV V2 flight controller schematic: 5 V-in power, RP2354B, sensors, logging, PWM
    Revision P3 schematic, fully generated by tools/build_power.py:
    - Power: 5V_IN (external BEC / 1S BMS-boost) and USB-C through two LM66100
    ideal diodes into V5_SYS with 220 uF polymer bulk; TPS62913 low-noise buck
    to V3V3_SYS with ferrite-bead output filter; TPS7A20-3.3 LDO to V3V3_ANA.
    - Ports: three 4-pin JST-GH (UART_GPS, UART_ELRS, I2C_MAG) on V3V3_SYS.
    - MCU: RP2354B with datasheet decoupling, digital domains on V3V3_SYS,
    ADC_AVDD/VREG_AVDD on V3V3_ANA, 12 MHz crystal, RUN from PWR_GOOD plus
    reset button, BOOTSEL, SWD, USB series resistors, 5V_IN/VBUS sense, LEDs,
    buzzer.
    - Sensors: BMI088, BMP58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
    [MARV-V2.before-power.kicad_sch, MARV-V2.kicad_pcb, MARV-V2.kicad_sch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]
2026-09-15 Schematic review: TPS2121 input stage, DS-009 ports, sequencing and CS fixes; docs trimmed
    Datasheet-grounded review of the full flight-controller schematic. Downstream
    of the input everything verified pin-by-pin (TPS62913, TPS7A20, RP2354B,
    BMI088/BMP581/ADXL375, W25Q128, microSD, PWM). The 5 V input stage did not:
    - LM66100 (5.5 V rec-op / 6 V abs-max) replaced by one TPS2121 mux (U25):
    BEC priority on IN1, OV lockout ~5.86 V, current limit ~1.5 A, reverse
    blocking on both inputs, source status on GPIO39. Input spec 4.75-5.5 V.
    - 5V_IN: 2x4.7 uF + 100 uF + SMAJ5.0A TVS; J3 JST-XH -> XT30PW-M (pin 1 GND).
    - J6/J7/J9 reordered to Pixhawk DS-009 (VCC/sig/sig/GND); GPS/ELRS VCC 5 V.
    - VIN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
    [MARV-V2.kicad_sch, actuators.kicad_sch, mcu.kicad_sch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]
2026-09-15 Replace BMI088 with ICM-45686; vendor all footprints and 3D models for layout
    Sensors: U21 is now the TDK ICM-45686 (single AP_CS on GPIO20 as IMU_CS,
    INT1/INT2 on GPIO23/24, GPIO21 spare, R49 dropped, VDD+VDDIO on V3V3_ANA
    with 100 nF + 1 uF each). Project-local symbol, footprint and stand-in STEP;
    footprint numbering verified against DS-000577 Rev 1.0 Sec 11.2 (CCW, top
    view). BMI088_SPI derived-symbol machinery removed from the generator.
    Layout readiness: new tools/audit_footprints.py checks every component for
    a resolvable footprint and present 3D model (128/128 OK). The seven official
    KiCad footprints whose STEP files are absent from kicad-packages3d 10.0.6
    are vendored into MARV_Pack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
    [mcu.kicad_sch, power_3v3.kicad_sch, power_bom.csv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]
2026-09-16 Physical design: VBAT-in buck, ESC pad row, pad-row IO, 50 mm single-sided board
    Power: the FC now takes raw 2-6S VBAT from the MicoAir AM32 4-in-1 ESC pad
    row (CURR TX M4 M3 M2 M1 VBAT GND, J3) through an AP63205WU 5 V/2 A buck
    (U26, XGL4030-472, 3 x 22 uF) into the existing TPS2121 mux; XT30 and its
    TVS removed. VBAT sense 100k/10k (36 V FS) on ADC0, ESC current sense on
    ADC2, ESC KISS telemetry on GPIO30.
    IO per the physical spec (DESIGN_SPEC "Physical design"): solder pad rows
    for GPS/ELRS/MAG (JST-GH removed), DBG and buzzer; 3x4 servo block for
    PWM5-8; 2x6 spare-IO block; WS2812C-2020 RGB LED replaces the two discrete
    LEDs; buzzer moved off-board to pads; flash socket is the 150-mil S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
    [MARV-V2.kicad_pcb, MARV-V2.kicad_sch, actuators.kicad_sch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]
2026-09-16 Remove buzzer; passives to 0201/0402; GPIO28 to spare-IO block
    Buzzer pads J15, driver Q20/D22/R33/R34 and the BUZZ nets removed; GPIO28
    now terminates on J16 pin 12 (was a second GND). Resistors 0201, caps
    <= 4.7 uF 0402, 22 uF/10 V 0603, 22 uF/25 V and 10 uF/50 V 0805, 47 uF
    0805; USB net-class clearance 0.18 mm so the 0201 series resistors on the
    pair pass DRC. Board regenerated at 50 x 50 mm (courtyard fill 63.5 %);
    DRC unrouted-only. 134 components, 105 nets; ERC 0/0, 213 pin mappings,
    run_power_checks PASS, audit 134/134.
    Claude-Session: https://claude.ai/code/session_01U6Ud7JA3CDTJZVcZZr5sx1
    [MARV-V2.kicad_pcb, mcu.kicad_sch, power_3v3.kicad_sch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]
2026-09-16 IO array replaces bus pad rows; PINOUT.md pin plan; test points; ESC/battery docs
    Left edge is now one 2 x 16 through-hole IO array (J6, signal | 5V/3V3/GND
    rows, madflight-style) carrying GPS/ELRS/MAG and the ten spare GPIOs; the
    J6/J7/J9 pad rows and the J16 block are gone. ESC pad row J3 and DBG pads
    J10 stay; servo block J12-J14 stays beside the ESC row. TP1-TP10 1 mm test
    points on the sensor SPI, chip selects and interrupts.
    PINOUT.md records every GPIO's function and alternates from RP2350
    datasheet Table 3, the spare-pin roles (I2C0 on 44/45, SPI1 on 46/47/28,
    ADC3-7) and the peripheral ledger; check_power_netlist.py now asserts all
    48 GPIO nets against it.
    DESIGN_SPEC: ESC connect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
    [MARV-V2.kicad_pcb, MARV-V2.kicad_sch, mcu.kicad_sch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]
2026-09-16 Madflight-style layout: 48.7 x 41.2 mm, ESC row left, 3x14 IO block right
    Board re-laid out to the madflight FC3v2 arrangement and shrunk from the
    50 x 50 square: rectangle 48.7 x 41.2 mm, 30.5 mm mounting square offset
    (7.0 mm left margin for the vertical ESC pad row J3, 11.2 mm right margin
    for the IO block), grommet keepout Ø6.5. The IO block is three abutting
    1x14 rows J6/J7/J8 (signal | 5V/3V3 | GND per row): T0 R0 T1 R1 SDA SCL
    S5-S8 A44-A47. The servo block and the 2x16 array are gone (actuators sheet
    removed); GPIO 1/21/27/28/31/43 are no-connect (PINOUT.md, checker
    updated). microSD ejects off the top edge, USB-C/RESET/BOOT/LED/DBG on the
    bottom edge, sensors + test points between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
    [MARV-V2.kicad_pcb, MARV-V2.kicad_sch, actuators.kicad_sch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]
2026-09-16 ESC row, DBG pads and test points to the back; board 46.6 x 41.2 mm; fixed IO-block silk
    The ESC pad row J3, the DBG pad row J10 and TP1-TP10 are placed flipped on
    B.Cu (bare pads only; assembly stays single-sided on the front). The back
    faces the ESC in the stack, so the 8-wire harness runs straight down; the
    labels are mirrored B.SilkS text in bands nothing else can reach. With the
    left margin freed, the left holes sit 4.0 mm from the edge and the board
    shrinks to 46.6 x 41.2 mm (39-40 mm heights fail the packer). The IO-block
    labels on the front are now fixed in a reserved band instead of being
    nudged, so no silk collides. DRC: unrouted items only, front and back.
    ERC 0/0, checker PASS (1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
    [MARV-V2.kicad_pcb]
2026-09-16 Flash socket becomes an optional back-side expansion; ESC row on the back edge; C19 100 uF
    U24 (SOIC-8 150 mil) and its caps C62/C63 are DNP, excluded from the BOM
    and placed flipped on the back with a legend ("FLASH / PSRAM EXPANSION,
    SOIC-8 150mil, QMI CS1, W25Q64JVSSIQ or APS6404L-3SQR-SN"); the RP2354B's
    internal 2 MB flash and the microSD cover firmware and logging. The ESC pad
    row J3 sits along the left edge on the back, like the DBG row on the bottom
    edge. C19 (V5_SYS bulk) reduced from 220 uF D-case to 100 uF 6.3 V B-case:
    the ngspice decks now use CPOLY=100u and every handover predicate still
    passes (worst-case V5_SYS min 4.37 V). Board 46.6 x 41.2 mm; DRC
    unrouted-only; ERC 0/0, ch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
    [MARV-V2.kicad_pcb, power_3v3.kicad_sch, power_bom.csv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]
2026-09-16 Flash-socket caps back on the front, minimal socket silk; L2 to XGL3020-222
    C62/C63 (U24 decoupling) are fitted on the front again, so a user adding a
    flash or PSRAM chip to the back-side SOIC-8 socket only solders the chip;
    the back legend is reduced to "FLASH" / "SOIC-8" plus the pin-1 mark, and
    the compatible parts (150-mil SOIC-8 QSPI NOR: W25Q16/32/64JVSS, GD25Q32C/
    64C, MX25L3233F/6433F; QSPI PSRAM: APS6404L-3SQR-SN, ESP-PSRAM64H, IPS6404L,
    LY68L6400) are documented in DESIGN_SPEC/LIBRARIES.
    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
    [MARV-V2.kicad_pcb, power_3v3.kicad_sch, power_bom.csv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]
2026-09-16 JLCPCB sourcing: Basic-part refactor, LCSC numbers in the schematic, order files and audit
    Parts audited line by line against JLCPCB's live catalogue (tools/jlc/,
    reports/jlc-audit.md). Resistors move 0201 -> 0402 (JLC's Basic library has
    no 0201 resistor), the U7 FB divider becomes 10k/3.16k 0.1 % (15.8k 0.1 % is
    not stocked), Y1 becomes TAXM12M4RFBCCT2T (CL 12 pF) with 18 pF loads, L2/L3
    become CJIANG FTC303020D2R2MBCA / FTC404030S4R7MGCA (stocked; Isat 5.5 A /
    6.0 A at 30 %, footprints + models vendored from KiCad), the 22 uF/25 V and
    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
    [MARV-V2.kicad_pcb, jlc-bom.csv, lcsc_map.csv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]
2026-09-17 Schematic re-organised into 11 per-subsystem pages, drawn as wired blocks
    Each subsystem now has its own sheet (RP2354B, USB/debug, ICM-45686, BMP581,
    ADXL375, microSD, QSPI expansion, VBAT buck + ESC row, priority mux, 3.3 V
    rail, IO block) with the IC's own decoupling, pull-ups, test points and
    connectors placed beside it and wired, labels only for nets leaving the
    block. Root sheet is an index. tools/build_power.py grows a small layout
    engine (wire routing, junctions, decoupling ladders, note flow) with
    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
    [MARV-V2.kicad_pcb, MARV-V2.kicad_sch, baro.kicad_sch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]
2026-09-17 Power tree: 5 V-in from an external BEC; drop pack buck, TPS2121 mux, TPS62913 stage and USB ESD
    Reverses the "pack-powered from the ESC" decision, which was made without
    the owner's agreement and inverted the stated requirement (5 V in from a
    BEC between the ESC and the FC, so any 2-6S BEC or a 1S boost works
    upstream). 140 -> 116 parts; JLC 46 -> 32 LCSC parts, 29 -> 17 Extended.
    - J3 ESC row 1x08 -> 1x09: pad 7 5V_IN, pad 8 GND, pad 9 VBAT (sense only,
    feeds the R27/R28/C48 divider on GPIO41; no zone, dropped from Power class)
    - USB/5V OR: Q1 AO3401A (gate on USB_VBUS, 100k pull-down) + D1 1N5819WS,
    both JLC Basic. IO-block 5 V rows, C19, C20, C21 move ahead of the FET
    onto 5V_IN;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
    [MARV-V2.kicad_pcb, MARV-V2.kicad_sch, baro.kicad_sch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]
2026-09-18 Configure JLCPCB DFM constraints and compact routing presets
    [MARV-V2.kicad_pcb]
2026-09-18 Save communication schematic, locking microSD and manual PCB updates
    [MARV-V2.kicad_pcb, lcsc_map.csv, mcu.kicad_sch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]
2026-09-18 Make DFM settings repeatable and purge obsolete design artifacts
    [MARV-V2.before-power.kicad_sch, MARV-V2.kicad_pcb, MARV-V2.kicad_sch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]
2026-09-21 finished routing
    [MARV-V2.kicad_pcb, io_block.kicad_sch]
2026-09-21 Normalise silkscreen for JLC, reorder MCU GPIOs, relax DFM guards
    - Silk strokes 0.15 mm, silk text 1.0/0.15 mm, no outlines on 0402 R/C and L2,
    compact no-silk test-point footprint (MARV_Packages), edge-connector silk
    trimmed inside the outline, one dangling GND via removed;
    lib_footprint_mismatch set to ignore in the DFM profile and documented.
    - MCU pin order: SD bus on GPIO28-33 (top-left corner), ESC row in J3 pad order
    (TELEM GPIO34, PWM4-1 GPIO36-39, CURR ADC1, VBAT ADC2), LED_DATA GPIO43;
    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
    [MARV-V2.kicad_pcb, baro.kicad_sch, highg.kicad_sch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]
2026-09-21 Order-ready: U24 via cleared, R58 sourced (C25092), fab and assembly exports
    - Owner moved the GND via out of U24's pad column: DRC now has no electrical
    errors, 0 unconnected, 0 schematic-parity issues (78 cosmetic courtyard
    gaps and 80 RP2350 pad-size review warnings remain).
    - R58 22 ohm 0402 gets LCSC C25092 in the schematic, the footprint field and
    tools/jlc/lcsc_map.csv.
    - build/ (ignored) holds Gerbers+drill (build/MARV-V2-gerbers.zip) and the
    JLC BOM/CPL (build/assembly/) generated from this commit.
    Claude-Session: https://claude.ai/code/session_01VST8gLViyNpcDEYyh3itUW
    [MARV-V2.kicad_pcb, lcsc_map.csv, mcu.kicad_sch]
2026-09-21 Move vias to JLC's free tier (0.45/0.30) and HASL; regenerate fab files
    - All 161 signal vias re-drilled 0.20 -> 0.30 mm (0.45 mm pad); one stray
    blind-typed via converted to a through via. JLC's order form priced the
    0.2 mm option at ~$38 of high-precision extras, so 0.3 mm is the floor.
    - DFM profile: min hole 0.3, via ring 0.075 (JLC's figure for 0.45-on-0.3),
    hole-to-copper 0.2 (JLC via spec), same-net hole-to-pad 0.15 (vias are
    ordered plugged), presets 0.45/0.30 and 0.60/0.30, finish HAL SnPb.
    - DRC: 0 unconnected, 0 parity, no electrical errors.
    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
    [MARV-V2.kicad_pcb]
2026-09-22 All vias 0.60/0.30 with the recommended 0.15 mm ring; DFM minimums restored
    - 162 signal vias 0.45 -> 0.60 mm pad on the 0.30 mm hole (owner's choice:
    re-route the tight spots rather than ship a 0.075 mm ring).
    - DFM profile back to via ring 0.15, via diameter 0.6, hole-to-copper 0.25,
    same-net hole-to-pad 0.2; single via preset 0.60/0.30.
    - DRC now lists 143 clearance/hole/mask conflicts at 74 vias (build/via_rework.csv,
    ignored) for the owner's re-route; 0 unconnected, 0 parity.
    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
    [MARV-V2.kicad_pcb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]
2026-09-22 DRC 0 err
    [MARV-V2.kicad_pcb, mcu.kicad_sch]
2026-09-22 Order-ready: core regulator per RP2350 §6.3.8, SWD header, second DVDD cap, README rewrite
    Core regulator (U20 / C39 / C45 / L20):
    - C39/C45 lands narrowed to 0.46 mm (0.50 mm gap) so VREG_LX passes between
    the pads as in datasheet Fig. 23; local 0.12 mm clearance rule for those
    two footprints only (inside JLC's 3.5 mil four-layer tier)
    - In1 GND cutout under L20 and the LX net (Fig. 24); single-point ground
    return with two adjacent vias; B.Cu GND pour tying the SD-cluster vias
    - L20 switched to the polarity-marked Abracon AOTA-B201610S3R3-101-T
    (LCSC C42411119) with a silk orientation dot at pad 2 / DVDD
    - C81 added: second 4.7 uF on DVDD at the far edge of the package
    - U22 BMP581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
    [MARV-V2.kicad_pcb, lcsc_map.csv, mcu.kicad_sch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]
2026-09-22 Top silkscreen: sensor axis marker (G1) and chevron (G2) as board-only footprints
    Logo_AxisMarker (6 mm, from images/axis_marker_y_right.svg) and Logo_Chevron
    (16 mm, straightened and mirrored from the bitmap trace in images/chevron.svg)
    added to MARV_Packages.pretty and placed on F.SilkS. Old axis marker SVG removed.
    [MARV-V2.kicad_pcb]
2026-09-22 Add PCB render gallery and first-boot review
2026-09-22 Move JLCPCB export to Fabrication Toolkit; drop tools/jlc scripts
    - Add fabrication-toolkit-options.json (auto translate + exclude DNP on;
    auto fill, V-cut, alternate outline, all-active-layer plotting off)
    - Mark hand-soldered headers and board-only footprints excluded from
    BOM/position files in both schematic and PCB (U24 stays DNP)
    - Remove tools/jlc/*, tools/jlc/lcsc_map.csv and power_bom.csv;
    the plugin now produces production/{MARV-V2.zip,bom.csv,positions.csv}
    - Ignore generated production/ output; update README and LIBRARIES.md
    Verified: 88 top-side placements, 34 LCSC parts, XY identical to prior
    export; ERC 0, DRC 0 errors / 0 unconnected / 0 parity issues.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
    [MARV-V2.kicad_pcb, baro.kicad_sch, highg.kicad_sch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]
2026-10-22 finished routing reg, gp under sd & flash, icm solder mask exclusion
